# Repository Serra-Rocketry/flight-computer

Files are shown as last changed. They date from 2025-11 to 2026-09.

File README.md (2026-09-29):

# Avionics — Onboard Computer

> **v2.0 Flight Computer** for Serra Rocketry (#11 - Dedalo).
>
> OOP + FreeRTOS + 4-state FSM, validated against real flight data.
> Built for the ESP32-S3.

## Overview

Real-time avionics firmware for a sounding rocket. Runs on an **ESP32-S3**
under FreeRTOS, reading barometric (BMP585), inertial (LSM6DS3) and GPS
(NEO-8M) sensors to detect flight events and deploy the parachute at apogee.

- **Flight state machine**: IDLE → ASCENT → DESCENT → LANDED, with sub-event
  flags (liftoff, burnout, apogee, freefall, parachute)
- **Parachute deployment**: Apogee + stable negative Vz, 3-cycle
  confirmation, 50 m ground guard — validated against RocketPy + real flight data points
- **Telemetry**: 22-field CSV over LoRa @ 915 MHz to ground receiver
- **Logging**: SD card (primary) with LittleFS flash fallback
- **Safety**: NaN/Inf rejection, sensor fallback, TWDT watchdog, multi-condition parachute logic

## Architecture

```
firmware/
├── firmware.ino          # setup()/loop() — orchestrates init*Task()
├── config.h              # Pins, thresholds, radio parameters
├── sensors/              # ISensor implementations (BMP585, LSM6DS3, GPS)
├── flight/               # FreeRTOS tasks + FlightStateMachine
├── modules/              # Actuators/peripherals (servo, LoRa, buzzer, FS)
└── docs/architecture.md  # v2.0 architecture (consolidated from REFACTORING_PLAN.md)
```

Two FreeRTOS cores with queue-based communication:

| Core  | Task | Priority | Rate  | Responsibility |
| ----- | --- | --- | ----- | --- |
| **1** | `FlightControlTask` | 20 | 5 Hz  | Sensors + FSM + parachute + watchdog  |
| **0** | `TelemetryTask` | 5 | 5 Hz  | GPS enrichment + LoRa + file + Serial |
| **0** | `LoggerTask` | 1 | — | Async log queue with level filter |

## Quick Start

### Arduino IDE (recommended)

1. Board: **ESP32-S3 Dev Module** (enable "USB CDC On Boot")
2. Open `firmware/firmware.ino`
3. Install libraries: `Adafruit BMP5xx`, `Adafruit LSM6DS3`, `TinyGPS++`,
   `ESP32Servo`, `LoRa by Sandeep Mistry`
4. Compile (`Ctrl+R`) and upload (`Ctrl+U`)

### Validate without hardware

```bash
python3 extras/FSM_tester/FSM_Tester.py       # FSM against 1,873 real data points
python3 extras/validate_telemetry_format.py    # 22-field telemetry alignment
```

## Key Specifications

| Parameter | Value |
| --- | --- |
| FlightControl rate | 5 Hz (200 ms) |
| Telemetry rate | 5 Hz (200 ms) |
| Parachute confirm  | 3 consecutive Vz < −2 m/s |
| Ground guard | 50 m AGL |
| LoRa frequency | 915 MHz (Brazil/Americas ISM) |
| LoRa config | SF7, BW 125 kHz, CR 4/5, CRC on, +17 dBm |
| Storage | SD card (SPI) → LittleFS fallback |
| Sensor queue | 25 slots (∼2.4 KB) |
| Log queue | 50 slots (∼7.2 KB) |

## Documentation

- [`docs/software.md`](docs/software.md) — Software architecture
|- [`docs/hardware.md`](docs/hardware.md) — Hardware specs, pinout, BOM
|- [`docs/architecture.md`](docs/architecture.md) — Architecture spec (consolidated)
|- [`docs/modules.md`](docs/modules.md) — Module reference
|- [`docs/flowchart.md`](docs/flowchart.md) — FreeRTOS + FSM flow diagram
- [`AGENTS.md`](AGENTS.md) — AI agent coding guide
- [`CONTRIBUTING.md`](CONTRIBUTING.md) — How to contribute

## Repository Layout

```
firmware/   v2.0 firmware (OOP + FreeRTOS + FSM)
test/       Hardware validation sketches (sensors, servo, FSM)
docs/       software.md, hardware.md, telemetry-format.md, flowchart.md
hardware/   KiCad schematic + PCB + BOM
extras/     Scripts, FSM tester, format validator, emergency deploy
```

## Status

All refactoring plan phases are **complete** — v2.0 is fully implemented and
documented. See [`CHANGELOG.md`](CHANGELOG.md) for the full release history.

## Team

Serra Rocketry — IPRJ/UERJ

## License

This project is licensed under the MIT License - see the [LICENSE](LICENSE) file for details.

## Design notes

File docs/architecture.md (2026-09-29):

# Architecture — Flight Computer v2.0

Architecture specification for the v2.0 firmware (OOP + FreeRTOS + 4-state FSM).
Consolidates the former `firmware/REFACTORING_PLAN.md` into a living reference.

## Overview

The v2.0 firmware migrates from the v1.0 procedural architecture to an
object-oriented design with selective POO (sensors only) and a strict
FreeRTOS multi-task separation between safety-critical (FSM + deploy) and
non-critical (telemetry/logging) paths.

**Hardware**: ESP32-S3 DevKitC-1-N8R8 (primary). ESP32-C3 SuperMini for the
emergency backup board (`extras/emergency/`).

## Design Decisions

| Aspect | Decision | Rationale |
|---|---|---|
| OOP | Selective | Only sensors that change became classes |
| FSM | Enum/Switch | Simple, low overhead |
| FreeRTOS | 3 Tasks | Separation: FSM (5 Hz) / Telemetry (5 Hz) / Logger |
| Migration | Big Bang | Full refactor in one pass |
| Tests | Hardware + Python | No C++ unit-test infra; FSM validated via Python port |
| Queue sizes | 25 (sensor), 50 (log) | Covers worst case with margin |
| Watchdog | 5s, armed inside FlightControlTask | Avoids TWDT armed with no task to reset it |
| Logging | Queue-based + Serial filter | Verbose dev, filtered in production |

## Architecture (post-5Hz fix)

### Directory layout

```
firmware/
├── firmware.ino                    # Entry point (setup + init*Task)
├── config.h                        # Pins, thresholds, radio/storage params
├── config.cpp                      # Config helpers
├── sensors/                        # OOP sensor abstraction (headers)
│   ├── ISensor.h                   # Abstract interface
│   ├── BMP585Sensor.h              # Barometer (alt, press, temp, Vz)
│   ├── LSM6DS3Sensor.h             # IMU (6-axis)
│   └── GPSModule.h                 # GNSS (non-blocking NMEA)
├── flight/                         # FSM + FreeRTOS tasks (headers)
│   ├── SensorData.h                # Shared structs + FlightState enum
│   ├── FlightStateMachine.h        # 4-state FSM + 7 sub-event flags
│   ├── FlightControlTask.h         # Task 1 — 5 Hz, Core 1, priority 20
│   ├── TelemetryTask.h             # Task 2 — 5 Hz, Core 0, priority 5
│   └── LoggerTask.h                # Task 3 — low priority
├── modules/                        # Actuators/peripherals (headers)
│   ├── parachute_module.h          # Servo owner
│   ├── lora_module.h               # 915 MHz radio
│   ├── buzzer_module.h             # Status tones
│   └── filesystem_module.h         # SD + LittleFS fallback
├── *.cpp                           # Implementations at sketch root
└── REFACTORING_PLAN.md             # This document (legacy source)
```

> `.cpp` files live at the sketch root because Arduino IDE only compiles
> sources at the root of the `.ino` sketch folder. Headers are organized in
> subfolders; PlatformIO can use `src/` with subdirectories natively.

### FreeRTOS task layout

| Core | Task | Priority | Rate | Responsibility |
|---|---|---|---|---|
| 1 | `taskFlightControl` | 20 (HIGH) | **5 Hz** (200 ms) | Sensors + FSM + deploy + queue + TWDT |
| 0 | `taskTelemetry` | 5 (LOW) | 5 Hz (200 ms) | GPS + queue drain + LoRa + storage + Serial |
| 0 | `taskLogger` | 1 | event | Async log queue consumer |

Inter-task communication via queues only — no shared variables:

- `sensorDataQueue` (25 slots) — FlightControl → Telemetry
- `logQueue` (50 slots) — any task → Logger

### Key tuning parameter: 5 Hz flight loop

> **Context**: Flight #51 (Thonyan, 2026-09-03) descended ballistically —
> parachute never deployed. Root cause: the flight loop ran at 50 Hz while the
> BMP585 effective conversion rate was ~25 Hz. `vz` alternated between 0.00
> (stale cycle) and 2×real (double step over the 20 ms dt). Both
> `PARACHUTE_CONFIRM_CYCLES=3` and `FREEFALL_BACKSTOP_CYCLES=50` — both
> consecutive-cycle gates — never survived the interleaved zeros.

**Fix** (`d0865ee`, `c5dd591`): `FLIGHT_CONTROL_PERIOD_MS` 20 → 200 ms.
All cycle-count constants rescaled to preserve the same **absolute times**:

| Constant | 50 Hz (old) | 5 Hz (new) | Absolute time |
|---|---|---|---|
| `FREEFALL_BACKSTOP_CYCLES` | 50 | 5 | 1.0 s |
| `BARO_STALE_SUSTAIN_CYCLES` | 125 | 13 | 2.6 s |
| `ARM_REZERO_SUSTAIN_CYCLES` | 150 | 15 | 3.0 s |
| `BARO_GLITCH_SUSTAIN_CYCLES` | 50 | 5 | 1.0 s |
| `LIFTOFF_ALT_CONFIRM_CYCLES` | 3 | 1 | 200 ms |
| `PARACHUTE_CONFIRM_CYCLES` | 3 | 3 | 0.6 s (unchanged — time-based) |

`LIFTOFF_CONFIRM_MS` (100 ms) and `LIFTOFF_CONFIRM_MAX_GAP_MS` (60 → 200 ms)
are per-time; `PARACHUTE_CONFIRM_CYCLES` is a count (3 = 600 ms at 5 Hz).

**Validation**: `extras/FSM_tester/validate_fsm_5hz.py` reproduces the failure
numerically — at 50 Hz with stale interleaving, deploy = `None` (blocked);
at 5 Hz, deploy at 317 m, +0.6 s after apogee, matching the real flight.

## Flight State Machine

4 outer states with internal sub-event flags (set once, diagnostic only):

| Outer state | Sub-events tracked |
|---|---|
| `IDLE` | — |
| `ASCENT` | `liftoff`, `burnout` |
| `DESCENT` | `apogee`, `freefall` |
| `LANDED` | `parachute` |

### Transitions

| From | To | Trigger |
|---|----|---|
| IDLE | ASCENT | `detectLiftoff()`: totalAccel > 15 m/s² sustained via `LIFTOFF_CONFIRM_MS` (100 ms) |
| ASCENT | DESCENT | `detectApogee()`: \|vz\| < 1.0 m/s (zero crossing / peak) |
| DESCENT | LANDED | `detectLanded()`: \|vz\| < 0.5 m/s and altitude < 2 m |

### Deploy logic (Option A — at apogee, not descent)

Parachute deploy is **not** a state transition — it is queried by
`FlightControlTask` via `detectParachute()`:

```cpp
bool FlightStateMachine::detectParachute(float height, float vz) const {
  if (height < PARACHUTE_MIN_ALTITUDE) return false;   // 50 m ground guard
  if (vz < PARACHUTE_CONFIRM_VZ) {                     // -2.0 m/s
    return (_parachuteConfirmCount >= PARACHUTE_CONFIRM_CYCLES);  // 3 cycles
  }
  return false;
}
```

Deploy is invoked by `FlightControlTask` when the FSM signals confirmation,
via `parachute_module`'s `ParachuteServo`. Validated against RocketPy
(apogee 951 m → deploy 949.5 m) and real flight (apogee 272 m → deploy 268 m).

### Safety validation

| Test | Scenario | Result |
|---|---|---|
| `validate_fsm_5hz.py` | 50 Hz stale-sensor model reproduces ballistic failure | PASS (deploy = None at 50 Hz, deploy at 317 m at 5 Hz) |
| `validate_50hz_noise.py` | Quantization noise up to 20× real | PASS (0 false apogees, 0 premature deploys) |
| `validate_freefall_backstop.py` | FSM stuck in IDLE/ASCENT | PASS (backstop deploys at apogee) |
| `validate_baro_stale.py` | Barometer frozen mid-flight | PASS (IMU-only deploy at t=19.6s) |
| `validate_watchdog_reboot.py` | TWDT reset during flight | PASS (NVS restores state, deploy on apogee) |
| `validate_arming.py` | Bench vibration false-liftoff | PASS (50 m arming guard survives 22–122 m/s² spikes) |

See also [`docs/modules.md`](modules.md) for the module-by-module API.

## Safety: Dual-layer deploy (FSM-independent backstop)

### Layer 1: FSM Option A
Apogee + 3 consecutive cycles of Vz < -2 m/s, 50 m ground guard.

### Layer 2: Freefall backstop (independent of FSM state)

Implemented in `FlightControlTask::checkFreefallBackstop()` — fires even if
the FSM is alive but stuck in the wrong state (e.g. NVS-restored ASCENT mid-descent,
or FSM in IDLE with no snapshot). Uses its own IIR-filtered accelerometer
(α=0.2), separate from FSM state:

```
totalAccel (IIR α=0.2) < 3.0 m/s²   per 5 consecutive cycles (1.0 s)
        AND vz < -5.0 m/s            (real descent, excludes burnout)
        AND altitude > 50 m          (ground guard)
        → deployParachute()         (idempotent via g_parachuteActuated)
```

**Decisions grounded in real flight data:**
- `vz < -5 m/s` is mandatory: accelerometer drops to ~0g shortly after burnout
  (rocket still ascending). Without this guard, the chute would deploy at ~190 m
  on the way up.
- 1.0 s window: real zero-g windows last 8–131 s; bench vibration spikes are
  transient (22–122 m/s²) and rejected by the window.
- Own IIR filter: works even when FSM state is corrupted.

**Behavior**: fires 1–3 s after FSM deploy in normal flight (never before);
with FSM stuck, deploys at 922 m (simulated) / 255 m (real) — always above
the 50 m floor.

## Safety: Post-watchdog recovery (NVS)

If the TWDT resets the system mid-flight:

1. `FlightStateMachine::begin()` calls `restoreFromNVS()`:
   - No valid snapshot (first boot, or previous flight ended LANDED → clean
     snapshot) → FSM starts fresh in IDLE.
   - Valid snapshot in ASCENT/DESCENT → FSM **resumes from saved state**
     (flags + confirmation counter), and `base_pressure` from launch site is
     restored to the BMP585 → altitude remains **absolute to launch elevation**
     (no re-zeroing at the reboot point).
2. Snapshot saved on every state transition, at deploy, and once at boot.
   `reset()` clears it.
3. `setupServo(keepOpen)`: if the snapshot says chute already deployed, the
   servo is **not** re-closed on boot (closing with chute out mid-air would
   release it).

Validated: `extras/FSM_tester/validate_watchdog_reboot.py` — PASS in 5
simulated flight phases + 4 real flight phases.

**Known limitations**: a reboot during the powered phase re-arms only if
acceleration > 15 m/s² persists after boot; a snapshot from an aborted flight
(before LANDED) can restore ASCENT on the ground — the `PARACHUTE_MIN_ALTITUDE`
guard prevents false deploy.

## Resource usage

| Component | RAM | Flash |
|---|-----|---|
| Base code | ~50 KB | ~200 KB |
| Adafruit libs | ~10 KB | ~50 KB |
| FreeRTOS overhead | ~2 KB | ~20 KB |
| Task stacks (3 × 8 KB avg) | 28 KB | — |
| Queues (25 + 50 slots) | ~8 KB | — |
| Sensor/FSM objects | ~5 KB | — |
| **Total** | **~103 KB** | **~270 KB** |

Available: 512 KB RAM (~20%); 8 MB flash (~3%).

## Change log (from REFACTORING_PLAN.md)

### 2026-08-04 — Freefall backstop (FSM-independent)
`checkFreefallBackstop()`: acc < 3 m/s² (own IIR) for 1.0 s + vz < -5 m/s +
h > 50 m → idempotent deploy. Validated in Python before C++
(`validate_freefall_backstop.py` — scenarios A–D, all PASS).

### 2026-08-04 — Watchdog post-reset recovery (NVS)
FSM persists snapshot to NVS (`Preferences`, namespace `flight`/key `fsm`):
state, flags, confirmation counter, `base_pressure`, `maxAltitude`.
`restoreFromNVS()` in `begin()`. `setupServo(keepOpen)` prevents re-closing
an already-deployed chute. Validated: `validate_watchdog_reboot.py` (9 scenarios).

### 2026-08-05 — Real-flight risk review (5 risks)
- **Risk 1** (barometer freezes mid-flight): resolved — `getLastReadingAgeMs()`
  + IMU-only `checkBaroStaleContingency()` (deploy if baro stale >2 s + acc <3
  m/s² + h > 50 m, validated `validate_baro_stale.py` A–D PASS).
- **Risk 3** (apogee lost to 50 Hz vz noise): not confirmed —
  `validate_50hz_noise.py` shows 100% apogee detection, 0 premature deploys,
  0 missed deploys up to 5 s after apogee.
- **Risk 5** (post-burnout oscillation loses apogee): resolved —
  apogee gate simplified to `|vz| < 1.0` only (removed `az` gate with ~0.81 m/s²
  margin). vz from barometer is immunized against oscillation by construction.

### 2026-05-09 — 5 Hz flight loop (Thonyan #51 fix)
`FLIGHT_CONTROL_PERIOD_MS` 20 → 200. See "Key tuning parameter: 5 Hz flight loop"
above. This is the single change that unblocked apogee deployment for
Dédalo II / Thonyan II.

### 2026-06-24 — All 10 phases complete
v2.0 firmware fully migrated to OOP + FreeRTOS + 4-state FSM. See `CHANGELOG.md`.

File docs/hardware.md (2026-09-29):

# Hardware Documentation - Onboard Computer

## Overview

The onboard computer uses an **ESP32-S3** microcontroller (the v2.0 target
platform) as its core, integrated with a barometric altimeter, GPS, IMU and a
LoRa communication module.

> **Note — prototype vs target**: the early dev firmware ran on an
> ESP32-C3 SuperMini; the v2.0 design (schematic `hardware/electronics/...`)
> uses the ESP32-S3. The pin assignments in `firmware/config.h` now target the
> S3. Re-map if migrating between boards.

## Main Platform

### ESP32-S3 (v2.0 target)

**Specifications**:

- **Processor**: Xtensa LX7 dual-core @ 240 MHz
- **RAM**: 512 KB (SRAM) + PSRAM (see module variant)
- **Flash**: 8 MB (N8R8) or 2 MB (N8R2) — confirm variant on BOM/purchase order
- **Peripherals**: UART, SPI, I2C, GPIO, ADC, Timer, USB-OTG
- **Wireless**: WiFi 802.11b/g/n + Bluetooth 5 (LE)
- **Size**: ESP32-S3-DevKitC-1 form factor

**Used Pins** (from `firmware/config.h`):

```
GPIO 4  → RST_LORA   (LoRa Reset)
GPIO 5  → DIO0_LORA  (LoRa Interrupt / TX-RX done)
GPIO 6  → BUZZER_PIN
GPIO 7  → SERVO_PIN  (Parachute servo PWM)
GPIO 8  → I2C_SDA    (BMP585/BMP280 + LSM6DS3)
GPIO 9  → I2C_SCL    (BMP585/BMP280 + LSM6DS3)
GPIO 10 → SS_LORA    (LoRa Chip Select)
GPIO 11 → LORA_MOSI  (LoRa SPI MOSI)
GPIO 12 → LORA_SCK   (LoRa SPI Clock)
GPIO 13 → LORA_MISO  (LoRa SPI MISO)
GPIO 14 → SD_CS_PIN  (SD Card Chip Select)
GPIO 17 → RX_GPS     (UART RX — GPS TX)  ⚠ bench-measured 2026-08-27, see note
GPIO 18 → TX_GPS     (UART TX — GPS RX)  ⚠ bench-measured 2026-08-27, see note
```

> **GPS pinout note (2026-08-27 bench measurement):** the GPS TX line
> physically arrives on GPIO17, not GPIO18 as previously documented from the
> schematic. `config.h` was corrected (RX_GPS=17, TX_GPS=18) and validated on
> hardware: NMEA at 9600 baud, 11 satellites, 3D fix. Always trust the raw
> sniffer (`test/gps_diag/`) over the schematic comment when they disagree.

**Power Supply**: 3.3V nominal (regulated by LM2596).

## Sensors

### 1. BMP585 - Barometric Pressure Sensor

**Function**: Altitude and atmospheric pressure (vertical velocity derived in firmware).

**Specifications**:

- **Pressure Range**: 300 - 1250 hPa
- **Relative Accuracy**: ±0.06 hPa (typ.)
- **Absolute Accuracy**: ±0.5 hPa (typ.)
- **Interface**: I2C
- **I2C Address**: 0x7E (bench-measured 2026-08-27; factory default is 0x76/0x77
  selected by CSB). **Fallback**: if the BMP585 is absent, the driver
  (`BMP585Sensor`) falls back to a **BMP280** at 0x76/0x77 — same satellite
  pattern (`BME280Sensor.cpp` in the #213 repo).

**Pinout**:

| Pin | Function | Connection |
|-----|---|---|
| VCC | Power | 3.3V |
| GND | Ground | GND |
| SCL | I2C Clock | GPIO 9 |
| SDA | I2C Data | GPIO 8 |

**Assembly**: Breakout direct solder on PCB.

### 2. LSM6DS3 - IMU (Accelerometer + Gyroscope)

**Function**: Acceleration and angular velocity (flight dynamics).

**Specifications**:

- **Accelerometer**: ±2, ±4, ±8, ±16 g (configurable)
- **Gyroscope**: ±125, ±250, ±500, ±1000, ±2000 °/s
- **Interface**: I2C
- **I2C Address**: 0x6B (bench-measured 2026-08-27; SDO strap selects 0x6A/0x6B)

**Pinout**:

| Pin | Function | Connection |
|-----|---|---|
| VCC | Power | 3.3V |
| GND | Ground | GND |
| SCL | I2C Clock | GPIO 9 |
| SDA | I2C Data | GPIO 8 |

**Assembly**: Breakout direct solder on PCB.

### 3. NEO-8M - GPS Module

**Function**: Geolocation and time synchronization.

**Specifications**:

- **Sensitivity**: -167 dBm (tracking)
- **Acquisition**: Cold ~26s, Hot ~1s
- **Accuracy**: ±2.5 m
- **Update Rate**: up to 10 Hz
- **Protocol**: NMEA 0183
- **Interface**: Serial UART (HardwareSerial, non-blocking in firmware)

**Pinout**:

| Pin | Function | Connection |
|-----|---|---|
| VCC | Power | 3.3V |
| GND | Ground | GND |
| RX | Serial RX | GPIO 21 (TX_GPS) |
| TX | Serial TX | GPIO 20 (RX_GPS) |

**Features**:

- Integrated ceramic antenna
- Frequency: L1 (1575.42 MHz)
- Constellations: GPS, GLONASS, Galileo, BeiDou

**Assembly**: Breakout direct solder on PCB.

### 4. RFM95W - LoRa Module

**Function**: Long-range wireless telemetry to the recovery receiver.

**Specifications**:

- **Frequency**: 915 MHz ISM (Americas/Brazil; matches receiver-lora)
- **Range**: ~4 km (open field, ideal conditions)
- **Data Rate**: 0.3 - 37.5 kbps (SF/BW dependent)
- **Transmit Power**: +17 dBm (firmware setting)
- **Sensitivity**: -139 dBm (SF12, BW 125 kHz)
- **Interface**: SPI

**Configuration (firmware `config.h` + `lora_module.h`)**:

- Frequency: 915 MHz
- Sync Word: 0xF3
- Spreading Factor: 7
- Bandwidth: 125 kHz
- Coding Rate: 4/5
- CRC: enabled

**Pinout** (matches `config.h` — SPI bus is remapped via `SPI.begin(4,2,3,5)` in `setupLoRa()`):

| Pin | Function | Connection |
|-----|---|---|
| VCC | Power | 3.3V |
| GND | Ground | GND |
| SCK | SPI Clock | GPIO 4 (LORA_SCK) |
| MOSI| SPI Data | GPIO 3 (LORA_MOSI) |
| MISO| SPI Data | GPIO 2 (LORA_MISO) |
| NSS | SPI CS | GPIO 5 (SS_LORA) |
| NRST| Reset | GPIO 6 (RST_LORA) |
| DIO0| TX/RX Int| GPIO 7 (DIO0_LORA) |

**Assembly**: Breakout direct solder on PCB.

### 5. MicroSD Card — Data Logging

**Function**: Primary flight-data storage. The firmware writes the 22-field
CSV telemetry log here; if the card is absent or fails to mount, logging
automatically falls back to LittleFS (internal flash).

**Interface**: SPI (shares the same SCK/MOSI/MISO bus as the RFM95W, with an
independent chip-select line).

**Pinout**:

| Pin | Function | Connection |
|-----|---|---|
| VCC | Power | 3.3V |
| GND | Ground | GND |
| SCK | SPI Clock | GPIO 4 (shared with LoRa) |
| MOSI| SPI Data | GPIO 3 (shared with LoRa) |
| MISO| SPI Data | GPIO 2 (shared with LoRa) |
| CS  | SPI CS | GPIO 12 (SD_CS_PIN) |

**Note**: Because SD and LoRa share one SPI bus, `setupStorage()` (SD probe)
runs *before* `setupLoRa()` inside `initTelemetryTask()`, and both backends
use the same `SPI` object remapped to GPIO 4/3/2. A card present at boot is
preferred; LittleFS is the safety net.

## Actuators

### Parachute Servo

**Function**: Release the parachute mechanism at apogee (FSM Option A).

**Specifications**:

- **Type**: Standard 5V servo with metal gears
- **Torque**: ~4.8 kg/cm @ 5V
- **Speed**: ~0.23 s/60°
- **Weight**: ~9 g

**Pinout**:

| Wire | Function |
|---|---|
| Brown | Ground |
| Red | +5V |
| Yellow/Orange | PWM Signal (GPIO 10, SERVO_PIN) |

**Positions** (see `parachute_module.h`):

- Closed (pre-flight): `CLOSED_POS`
- Open (deployed): `OPEN_POS`

### Buzzer - Audio Signaling

**Function**: Initialization status indicator.

**Specifications**:

- **Type**: Active buzzer (5V)
- **Frequency**: ~2.7 kHz
- **Volume**: ~85 dB
- **Current**: ~30 mA

**Pinout**:

- Positive → 5V (via current-limiting resistor)
- Negative → GPIO 11 (BUZZER_PIN)

**Signals**:

- 3 short beeps = Initialization failure
- Beep sequence = Successful initialization

## Power Supply

### LM2596 - DC-DC Step Down Converter

**Function**: Regulate battery voltage to 3.3V / 5V.

**Specifications**:

- **Input**: 4.5 - 40V
- **Output 1**: 3.3V @ 3A (ESP32, I2C sensors)
- **Output 2**: 5V @ 3A (servo, buzzer, LoRa)
- **Frequency**: 150 kHz
- **Efficiency**: ~85%

### Batteries

**Configuration**: 3x 18650 in parallel

- **Nominal Voltage**: 3.7V
- **Capacity**: ~6000 mAh
- **Estimated Autonomy**: ~4-6 hours

## Printed Circuit Board (PCB)

### KiCad Files

- **[CDB.kicad_pro](../hardware/CDB/CDB.kicad_pro)** - Project file
- **[CDB.kicad_sch](../hardware/CDB/CDB.kicad_sch)** - Schematic
- **[CDB.kicad_pcb](../hardware/CDB/CDB.kicad_pcb)** - Board layout
- **[CDB.step](../hardware/CDB/CDB.step)** - 3D model

### Connectors

- **J2**: Servo motor (3 pins)
- **Power Connector**: 2 pins for 18650

### Approximate Dimensions

- **Length**: 125 mm
- **Width**: 50 mm
- **Height** (with components): ~30 mm

## Component List (BOM)

See [CDB_bom.md](../hardware/CDB_bom.md) for the complete list.

### Main Electronic Components

| Label | Component | Quantity | Function |
|---|---|---|---|
| A2 | ESP32-S3 (DevKitC-1) | 1 | Microcontroller (v2.0 target; N8R8 or N8R2 — confirm) |
| A3 | BMP585 Breakout | 1 | Pressure/altitude sensor |
| — | LSM6DS3 Breakout | 1 | IMU |
| M3 | LM2596 | 1 | Voltage regulator |
| M4 | NEO-8M | 1 | GPS |
| RFM95W1 | RFM95W LoRa | 1 | Wireless telemetry |
| SD1 | MicroSD card module | 1 | Flight-data logging (SPI, GPIO 12 CS) |
| J1 | 5V Buzzer | 1 | Signaling |
| J2 | Servo motor | 1 | Parachute control |

### Passive Components

- Capacitors: 100 nF, 10 μF, 220 μF
- Resistors: 1k, 10k, 100k Ohm
- Connectors: Pins, JST

## Block Diagram

```
┌─────────────────────────────────────────────────────────────┐
│                  ONBOARD COMPUTER                            │
├─────────────────────────────────────────────────────────────┤
│  ┌──────────┐  ┌──────────┐  ┌──────────┐  ┌──────────┐    │
│  │ BMP585   │  │ LSM6DS3  │  │ NEO-8M   │  │ RFM95W   │    │
│  │Barometer │  │   IMU    │  │   GPS    │  │  LoRa    │    │
│  └────┬─────┘  └────┬─────┘  └────┬─────┘  └────┬─────┘    │
│       │ I2C         │ I2C         │ UART         │ SPI     │
│       └─────────────┼─────────────┼──────────────┤        │
│              ┌──────┴─────────────┴──────┬────────┴────┐   │
│              │      ESP32-S3 (DevKitC-1)   │             │   │
│              │  FreeRTOS: FlightControl  │  Telemetry  │   │
│              │  (50Hz) → FSM → Servo     │  (5Hz) LoRa │   │
│              └────┬──────────┬───────────┴─────┬───────┘   │
│        GPIO PWM  │          │  GPIO BUZZER     │ SPI       │
│    ┌─────────────▼┐    ┌────▼──────┐    ┌──────▼────┐      │
│    │ Servo Motor  │    │ Buzzer    │    │ RFM95W    │      │
│    └──────────────┘    └───────────┘    └───────────┘      │
│  ┌──────────────────────────────────────────────────────┐  │
│  │          LM2596 DC-DC Converter                      │  │
│  │  Input: 3.7V (3x18650 parallel)  →  Output: 3.3V and 5V  │  │
│  └──────────────────────────────────────────────────────┘  │
└─────────────────────────────────────────────────────────────┘
```

## Support/Test Code

Individual test code is in [../test/](../test/):

- `test/basico/basico.ino` — general diagnostics
- `test/buzzer/buzzer.ino` — buzzer
- `test/lora/lora.ino` — LoRa
- `test/testeGPS/testeGPS.ino` — GPS
- `test/servo/servo.ino` — servo
- `test/LittleFS/LittleFS.ino` — storage
- `test/FSM/FSM.ino` — FSM reference (validated)

## Preliminary Tests

- Check continuity with multimeter
- Power on and check LEDs/buzzer
- Use basic test code

## Operation Notes

- **Encapsulation**: isolating capsule inside rocket
- **Shock**: Maximum acceleration tolerance not yet measured

## References

- [ESP32-S3 Datasheet](https://www.espressif.com/sites/default/files/documentation/esp32-s3_datasheet_en.pdf)
- [BMP585 Datasheet](https://www.bosch-sensortec.com/products/environmental-sensors/pressure-sensors/bmp585/)
- [LSM6DS3 Datasheet](https://www.st.com/resource/en/datasheet/lsm6ds3.pdf)
- [NEO-8M GPS Module](https://www.u-blox.com/en/product/neo-8m-series)
- [RFM95W LoRa Module](https://www.semtech.com/products/wireless-rf/lora-transceivers/rfm95w)

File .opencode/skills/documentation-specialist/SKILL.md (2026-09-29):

---
name: documentation-specialist
description: Technical writer and documentation specialist for embedded systems and aerospace projects.
license: MIT
compatibility: opencode
---

## Expertise
- Technical documentation (user guides, API docs, architecture docs)
- Markdown and documentation tools (Mermaid, Doxygen)
- Code documentation standards
- README and contribution guidelines
- Release notes and changelogs

## Responsibilities
1. **Maintain Project Documentation**
   - Keep README.md up to date
   - Update CHANGELOG.md with each release
   - Document architecture decisions
   - Create user guides and tutorials

2. **Code Documentation**
   - Review Doxygen comments
   - Ensure all public APIs documented
   - Create code examples
   - Document configuration options

3. **Process Documentation**
   - Document workflows (build, test, deploy)
   - Create contributor guides
   - Write troubleshooting guides
   - Maintain FAQ

## Project Documentation Structure

```
flight-computer/
├── README.md                    # Project overview
├── CHANGELOG.md                 # Version history
├── CONTRIBUTING.md              # How to contribute
│
├── docs/
│   ├── hardware.md              # Hardware specifications
│   ├── software.md              # Software architecture
│   ├── flowchart.md             # System flowcharts
│   └── CDB.png                  # Block diagram
│
├── firmware/
│   ├── MODULOS.md               # Module documentation
│   ├── REFACTORING_PLAN.md      # v2.0 architecture
│   └── [code files with Doxygen comments]
│
└── extras/
    └── FSM_tester/
        └── explicacao.md        # FSM explanation
```

## Documentation Standards

### README.md Structure
```markdown
# Project Name

[Badge: Build Status] [Badge: License] [Badge: Version]

## Overview
Brief description of the project (2-3 sentences)

## Features
- Feature 1
- Feature 2

## Hardware Requirements
- Component 1
- Component 2

## Software Requirements
- Library 1
- Library 2

## Quick Start
1. Step 1
2. Step 2

## Documentation
- [Hardware Guide](docs/hardware.md)
- [Software Guide](docs/software.md)

## Contributing
See [CONTRIBUTING.md](CONTRIBUTING.md)

## License
[License information]

## Team
Team #100 - Serra Rocketry
```

### CHANGELOG.md Format
**Follow**: [Keep a Changelog](https://keepachangelog.com/)

```markdown
# Changelog

All notable changes to this project will be documented in this file.

The format is based on [Keep a Changelog](https://keepachangelog.com/en/1.0.0/),
and this project adheres to [Semantic Versioning](https://semver.org/spec/v2.0.0.html).

## [Unreleased]

### Added
- New feature X

### Changed
- Modified behavior Y

### Fixed
- Bug Z

## [2.0.0] - 2026-XX-XX

### Added
- FreeRTOS multi-task architecture
- 7-state FSM with validated thresholds
- BMP585 and LSM6DS3 sensor support
- OOP sensor abstractions (ISensor interface)

### Changed
- Migrated from procedural to OOP design
- Replaced BMP280 with BMP585
- Replaced MPU6050 with LSM6DS3

### Removed
- Old procedural sensor modules

## [1.0.0] - 2026-01-27

### Added
- Initial release
- BMP280 barometric sensor support
- MPU6050 IMU support
- GPS NEO-6M integration
- LoRa telemetry (RFM95W)
- Parachute deployment logic
- LittleFS data logging
- WiFi AP for data recovery

[Unreleased]: https://github.com/team100/flight-computer/compare/v2.0.0...HEAD
[2.0.0]: https://github.com/team100/flight-computer/compare/v1.0.0...v2.0.0
[1.0.0]: https://github.com/team100/flight-computer/releases/tag/v1.0.0
```

### Code Documentation (Doxygen)

#### File Header
```cpp
/**
 * @file BMP585Sensor.h
 * @brief BMP585 barometric pressure sensor driver with altitude calculation
 * 
 * This module provides an interface to the Bosch BMP585 barometric pressure
 * sensor. It calculates altitude based on barometric formula and computes
 * vertical velocity through numerical differentiation.
 * 
 * @author Team #100 - Serra Rocketry
 * @date 2026-04-01
 * @version 2.0.0
 * 
 * Hardware Requirements:
 * - BMP585 sensor connected via I2C
 * - I2C address: 0x77 (SDO high) or 0x76 (SDO low)
 * - Pull-up resistors: 4.7kΩ (internal to ESP32-C3)
 * 
 * Usage Example:
 * @code
 * BMP585Sensor baro;
 * 
 * void setup() {
 *   if (!baro.begin()) {
 *     Serial.println("Sensor initialization failed");
 *   }
 * }
 * 
 * void loop() {
 *   baro.update();
 *   float alt = baro.getAltitude();
 *   float vz = baro.getVerticalVelocity();
 * }
 * @endcode
 * 
 * @see firmware/REFACTORING_PLAN.md for architecture details
 * @see docs/hardware.md for wiring diagram
 */
```

#### Function Documentation
```cpp
/**
 * @brief Initializes the BMP585 sensor and calibrates base pressure
 * 
 * This function performs the following steps:
 * 1. Establishes I2C communication with sensor
 * 2. Verifies sensor ID (0x50 for BMP585)
 * 3. Configures oversampling and IIR filter
 * 4. Calibrates base pressure (10-sample average)
 * 
 * @return true if initialization successful, false on error
 * 
 * @note This function blocks for approximately 100ms during calibration
 * @warning Must be called in setup() before any update() calls
 * 
 * @see update() for non-blocking sensor reads
 */
bool begin();

/**
 * @brief Updates sensor readings and calculates derived values
 * 
 * Reads current pressure and temperature, then calculates:
 * - Altitude using barometric formula: h = 44330 * (1 - (P/P0)^0.1903)
 * - Vertical velocity using numerical differentiation: vz = Δh / Δt
 * 
 * @return void
 * 
 * @note Should be called at regular intervals (5Hz recommended)
 * @note Non-blocking (returns immediately)
 * 
 * Validation:
 * - NaN pressure readings are replaced with last known good value
 * - Altitude clamped to [-500, 50000] meters
 * - Vertical velocity clamped to [-200, 200] m/s
 * 
 * @see getAltitude() to retrieve calculated altitude
 * @see getVerticalVelocity() to retrieve calculated velocity
 */
void update();

/**
 * @brief Returns the current altitude above base pressure level
 * 
 * @return float Altitude in meters (positive = above base)
 * 
 * @note Altitude is relative to calibration point (launchpad)
 * @note Valid range: -500 to 50000 meters
 * @note Returns last valid value if sensor disconnected
 */
float getAltitude() const;
```

### Architecture Documentation

#### Decision Record Template
**File**: `docs/adr/001-freertos-migration.md`

```markdown
# ADR 001: Migrate to FreeRTOS Architecture

**Status**: Accepted  
**Date**: 2026-03-15  
**Deciders**: Team #100  

## Context
Current v1.0 firmware uses single-threaded Arduino loop() running at 5Hz.
This creates several issues:
1. Slow FSM response time (200ms loop period)
2. Cannot prioritize flight-critical tasks
3. Telemetry logging blocks flight control
4. Underutilizes ESP32 dual-core processor

## Decision
Migrate to FreeRTOS multi-task architecture with 3 tasks:
- **FlightControl**: 50Hz, Core 1, Priority 20 (flight-critical)
- **Telemetry**: 5Hz, Core 0, Priority 5 (non-critical)
- **Logger**: Low priority, Core 0 (background)

## Rationale
- **Real-time response**: 20ms FSM update vs 200ms previously
- **Prioritization**: Flight safety takes precedence over logging
- **Core separation**: Flight logic isolated from I/O operations
- **Scalability**: Easy to add tasks (e.g., camera control)

## Consequences

### Positive
- 10x faster FSM response time
- Flight control never blocked by slow operations
- Better CPU utilization (both cores active)
- Industry-standard RTOS patterns

### Negative
- Increased complexity (task synchronization)
- Higher RAM usage (~15KB for RTOS overhead)
- Requires mutex/queue understanding
- Longer development time (estimated +8 hours)

## Alternatives Considered
1. **Keep single-threaded** - Rejected: Too slow for safety-critical FSM
2. **Custom cooperative scheduler** - Rejected: Reinventing the wheel
3. **Bare metal dual-core** - Rejected: Complex synchronization

## Implementation
See `firmware/REFACTORING_PLAN.md` Phase 7 for details.

## References
- ESP32 Technical Reference Manual, Chapter 3 (RTOS)
- FreeRTOS Documentation: Task Priorities
- Similar implementation: Teensy Flight Computer (MIT Rocket Team)
```

### Mermaid Diagrams

#### FSM State Diagram
```markdown
## Flight State Machine

```mermaid
stateDiagram-v2
    [*] --> IDLE
    IDLE --> LIFTOFF: totalAccel > 15 m/s²<br/>height > 5m
    
    LIFTOFF --> BURNOUT: az < -8 m/s² OR<br/>totalAccel < 2 m/s²
    
    BURNOUT --> APOGEE: |vz| < 1 m/s AND<br/>az < -0.1 m/s²
    
    APOGEE --> FREEFALL: totalAccel < 11.5 m/s² AND<br/>vz < -5 m/s
    
    FREEFALL --> PARACHUTE: altitude < 750m OR<br/>|vz| > 80 m/s
    
    PARACHUTE --> LANDED: |vz| < 0.5 m/s AND<br/>height < 10m
    
    LANDED --> [*]
    
    note right of IDLE
        Initialize sensors
        Calibrate base pressure
    end note
    
    note right of PARACHUTE
        Deploy parachute
        Start WiFi AP
        Beacon buzzer
    end note
\```
```

#### Task Interaction Diagram
```markdown
## FreeRTOS Task Architecture

```mermaid
graph TB
    subgraph "Core 1 - Flight Critical"
        FC[FlightControl Task<br/>50Hz, Priority 20]
        FSM[Flight State Machine]
        SENS[Sensor Updates]
        PARA[Parachute Control]
        
        FC --> FSM
        FC --> SENS
        FSM --> PARA
    end
    
    subgraph "Core 0 - Non-Critical"
        TEL[Telemetry Task<br/>5Hz, Priority 5]
        LOG[Logger Task<br/>Low Priority]
        
        TEL --> LORA[LoRa Transmit]
        TEL --> SERIAL[Serial Output]
        LOG --> FS[File System]
    end
    
    subgraph "Shared Resources"
        QUEUE[(Sensor Data Queue)]
        MUTEX{Altitude Mutex}
    end
    
    FC -->|xQueueSend| QUEUE
    TEL -->|xQueueReceive| QUEUE
    
    FC -->|xSemaphoreTake| MUTEX
    TEL -->|xSemaphoreTake| MUTEX
    
    style FC fill:#f96,stroke:#333,stroke-width:2px
    style TEL fill:#9cf,stroke:#333,stroke-width:2px
    style LOG fill:#9cf,stroke:#333,stroke-width:2px
\```
```

## Documentation Review Checklist

### For New Features
- [ ] README.md updated with feature description
- [ ] CHANGELOG.md updated (Unreleased section)
- [ ] API documentation (Doxygen comments)
- [ ] Usage examples provided
- [ ] Hardware requirements documented (if applicable)
- [ ] Configuration options explained

### For Bug Fixes
- [ ] CHANGELOG.md updated (Fixed section)
- [ ] Root cause documented in issue/PR
- [ ] Prevention strategy explained

### For Refactoring
- [ ] Architecture Decision Record created
- [ ] Migration guide provided
- [ ] Breaking changes documented
- [ ] CHANGELOG.md updated (Changed section)

## Tools

### Generate Doxygen Docs
```bash
# Install Doxygen
sudo apt install doxygen graphviz

# Generate documentation
cd firmware
doxygen Doxyfile

# View in browser
firefox html/index.html
```

### Mermaid Live Editor
https://mermaid.live/

### Markdown Linting
```bash
# Install markdownlint
npm install -g markdownlint-cli

# Lint documentation
markdownlint docs/**/*.md
```

## Resources
- Project documentation: `docs/`
- Doxygen manual: https://www.doxygen.nl/
- Mermaid syntax: https://mermaid.js.org/
- Keep a Changelog: https://keepachangelog.com/
- Semantic Versioning: https://semver.org/

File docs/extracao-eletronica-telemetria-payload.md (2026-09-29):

# Extração — Setor de Eletrônica, Telemetria e Payload

> **Fonte:** repositório `flight-computer` (branch `dev-2026`, HEAD `130149c`)
> **Para:** preenchimento do relatório do setor (competição 7ª LASC)
> **Data da extração:** 2026-08-06
> **Status:** v2.0 implementada (firmware completo em OOP); eletrônica em
> transição — schematic v2.0 existe mas PCB de voo ainda não roteada

---

## 1. System Architecture & CONOPS

### 1.1 Descrição geral do sistema eletrônico

O computador de voo é um sistema embarcado baseado em **ESP32-S3**
(DevKitC-1 N8R2), dois núcleos, 8 MB Flash, 2 MB PSRAM, executando
**FreeRTOS** com arquitetura orientada a objetos (v2.0). O sistema é
projetado para missões de foguetes suborbitais de curta duração (até
20 minutos), com a responsabilidade crítica de **abrir o paraquedas no
apogeu** de forma autônoma e sem feedback de confirmação mecânica.

O projeto transita de uma PCB protótipo (ESP32-C3 SuperMini + BME280 +
ICM-20602, uma camada, 4 componentes SMD) para a placa definitiva v2.0
(ESP32-S3 + BMP585 + LSM6DS3 + GPS M8N + LoRa 915 MHz + SD + step-down),
cujo schematic existe mas ainda não foi roteado. Durante a fase atual, o
firmware v2.0 é validado na placa DevKitC em bancada.

**Princípios de projeto do firmware:**
- Todas as decisões de deploy do paraquedas são **one-shot** (uma única
  vez, idempotente) e baseadas em **múltiplas camadas de redundância**
  independentes entre si.
- Dados de voo são gravados localmente (SD ou flash interna) como fonte
  primária; a telemetria LoRa é *best-effort* — o sistema nunca para de
  gravar por causa do link de rádio.
- Se qualquer componente de sensor falha, o sistema **não para** — usa
  fallbacks para os últimos valores válidos ou sensores redundantes.

### 1.2 Subsistema de hardware

| Subsistema | Componente | Função | Interface | Observações |
|---|---|---|---|---|
| Processador | ESP32-S3 DevKitC-1 N8R2 | Controle central,FreeRTOS, 2 núcleos | — | 240 MHz, 512 KB SRAM, 8 MB Flash, 2 MB PSRAM |
| Barômetro | BMP585 (Bosch) | Altitude barométrica, pressão, temperatura, Vz derivado no firmware | I2C (0x77) | 300–1250 hPa; ±0,5 hPa absoluta, ±0,06 hPa relativa; resolução ~0,01 hPa |
| IMU | LSM6DS3 (STMicroelectronics) | Aceleração (±16 g) e giroscópio (±2000 °/s) | I2C (0x6A) | Usado como sensor primário para detecção de queda livre (backstop) e contingência do barômetro congelado |
| GPS | u-blox NEO-8M / M8N | Geolocalização (lat/lon/alt) e tempo (nome do arquivo CSV) | UART (NMEA, não-bloqueante) | Multi-constelação: GPS + GLONASS + Galileo + BeiDou; sensibilidade −167 dBm; fix cold 26 s, hot 1 s |
| Telemetria | RFM95W HopeRF | Link de rádio LoRa 915 MHz (Brasil/Américas) | SPI (SCK=4, MISO=2, MOSI=3, CS=5, RST=6, DIO0=7) | SF7, BW125 kHz, CR 4/5, CRC on, TX +17 dBm; alcance ~4 km campo aberto |
| Armazenamento primário | MicroSD (SPI) | Gravação CSV 22 campos a 5 Hz (~4 KB/s) | SPI (bus compartilhado com LoRa, CS=12) | Cartão class 10; formato FAT32 |
| Armazenamento fallback | LittleFS (flash interna) | Fallback automático se SD falhar | Interno (NVS flash) | Capacidade limitada (~4 MB); se SD e LittleFS falharem, dados vão apenas para Serial |
| Atuador | Servo metálico ~4,8 kg·cm | Libera a porta do compartimento do paraquedas no apogeu | PWM (GPIO 7) | **50° (fechado) → 135° (ejeção)** — ângulos de bancada 2026-08-27; acionamento one-shot, sem feedback mecânico |
| Sinalização | Buzzer **passivo** | Beeps de status na inicialização (sucesso/falha) e alarme em safe-hold | GPIO 6 | Piezo passivo: exige onda quadrada via `tone()`/LEDC; **ressonância 2700 Hz** (varredura de bancada 27/08) — DC não produz som |
| Potência (estágio 1) | XL4015 step-down 5 A | Conversão DC-DC bateria → 5 V (servo, buzzer, GPS) | — | Substituiu o Mini-560 (27/08) após colapso sob pico do servo na bateria (unidade defeituosa; ver FMECA F16). Dropout ~1,5-2 V (assíncrono) — headroom aperta com 2S em fim de descarga |
| Potência (baterias) | 3× 18650 Li-ion paralelo | Fonte primária de energia | — | 3,7 V nominal, ~6000 mAh total; autonomia estimada 4–6 h |

### 1.3 Arquitetura de software (FreeRTOS)

O firmware é estruturado em três tarefas FreeRTOS concorrentes, duas
executadas no Core 0 (comunicação/armazenamento) e uma no Core 1
(controle de voo em tempo real). A comunicação entre tarefas ocorre
exclusivamente via filas (queues) — não há variáveis compartilhadas entre
tasks, eliminando condições de corrida por construção.

**Tarefa 1 — `taskFlightControl` (Core 1, prioridade 20, 50 Hz)**
Responsabilidade: leitura sequencial dos sensores (BMP585 → LSM6DS3),
execução da FSM, detecção e acionamento do paraquedas, alimentação do
watchdog (TWDT), coleta de métricas de execução (ciclos, overruns, queue
drops, tempo máximo de ciclo). Esta é a tarefa mais crítica do sistema
— sua perda (travamento) ativa o watchdog e provoca reboot, mas o estado
da FSM é restaurado do NVS, garantindo que o deploy possa ocorrer mesmo
após o reboot.

**Tarefa 2 — `taskTelemetry` (Core 0, prioridade 5, 5 Hz)**
Responsabilidade: atualização não-bloqueante do GPS (NMEA feed), drenagem
da fila de sensores (consome apenas a amostra mais recente, descartando
backlog de 200 ms), enriquecimento com fix GPS, montagem do CSV 22 campos
via `snprintf` (uma única conversão — não fragmenta heap), fan-out em três
canais simultâneos: Serial (debug), LoRa (receptor em solo) e arquivo
(SD ou LittleFS). O formato CSV é idêntico ao esperado pelo receptor
`recovery-webui/components/receiver-lora`.

**Tarefa 3 — `taskLogger` (Core 0, prioridade baixa, evento)**
Responsabilidade: recebe mensagens da fila de logs (50 slots) com filtro
de nível e imprime no Serial. Usado para diagnóstico e rastreio de
eventos de segurança (ARM, deploy, erros de watchdog).

**Parâmetros-chave de execução:**

| Parâmetro | Valor | Justificativa |
|---|---|---|
| Período FlightControl | 20 ms (50 Hz) | Resolução suficiente para detectar apogeu com 20 ms de latência (vz muda ~0,5 m/s por ciclo no apogeu) |
| Período Telemetry | 200 ms (5 Hz) | Balanço entre taxa de amostragem para o receptor e janela de TX LoRa |
| Tamanho da fila de sensores | 25 slots | FlightControl produz 10× mais rápido que Telemetry; fila absorve variações de timing |
| Tamanho da fila de logs | 50 slots | Suficiente para burst de logs durante初始化 |
| Stack da FlightControlTask | 8192 bytes | Mínimo necessário para BMP585Sensor + LSM6DS3Sensor + FlightStateMachine + buffers |
| Stack da TelemetryTask | 4096 bytes | GPSModule + montagem de String (snprintf em buffer fixo 256 bytes) |
| Timeout do watchdog | 10 s | Mais longo que o período de voo (~10 s até apogeu), para não reiniciar durante a subida |

### 1.4 Lógica algorítmica de acionamento da recuperação

O sistema de recuperação é a função mais crítica do computador de voo.
Ele é implementado como uma **Finite State Machine (FSM) de 4 estados**
com 7 flags de sub-evento, projetada com múltiplas camadas de defesa
independentes para garantir que o paraquedas abra mesmo em caso de falhas
cascata.

**FSM principal:** `IDLE → ASCENT → DESCENT → LANDED`

**Sub-eventos (flags booleanas, uma vez setadas nunca são limpas até reset):**
- `liftoff`: aceleração total > 15,0 m/s² (3× gravidade — limiar acima
  de qualquer vibração realista no solo)
- `burnout`: aceleração na direção vertical < −8 m/s² OU aceleração
  total < 2 m/s², com altitude > 50 m e vz > 2 m/s (sub-evento
  informativo, não muda o estado)
- `apogee`: |vz| < 1,0 m/s (detecção por vz do barômetro; o gate de az
  foi removido em 2026-08-05 por pêndulo/bias do acelerômetro em voo real)
- `freefall`: aceleração total < 3 m/s² + vz < −5 m/s + altura > 100 m
- `parachute`: detectado pelo `detectParachute()` (abaixo)

**Cadeia de deploy (Opção A — abre no apogeu, inegociável):**

1. **Armamento na rampa (risco nº2):** antes do voo, o operador envia o
   comando `ARM` via Serial. O firmware limpa o snapshot NVS, re-captura
   a `base_pressure` (pressão atmosférica local) e zera o `maxAltitude`.
   Se a altitude derivar mais de −10 m por 3 s na rampa (drift do
   barômetro por mudança de temperatura), o sistema faz *re-zero*
   automático da pressão base. O ARM é recusado se o voo já começou
   (`maxAltitude > 10 m`) ou se o paraquedas já foi aberto.

2. **Liftoff:** quando a aceleração total (vetor filtrado com IIR,
   α=0,2) ultrapassa 15,0 m/s² por três ciclos consecutivos, a FSM
   transita de `IDLE` para `ASCENT`. A filtragem IIR com semente no
   primeiro valor real evita transições falsas por ruído de arranque.

3. **Apogeu:** quando |vz| cruza 1,0 m/s (vz do barômetro), a FSM
   transita de `ASCENT` para `DESCENT` e zera o contador de confirmação
   do paraquedas. A remoção do gate de az resolveu o problema de pêndulo
   onde o bias do acelerômetro (az = +2,81 m/s² em repouso no voo real)
   impedia a detecção do apogeu.

4. **Confirmação de descida (anti-oscilação):** o deploy do paraquedas
   requer `vz < −2,0 m/s` por **3 ciclos consecutivos** (60 ms a 50 Hz).
   Se durante esses ciclos o vz voltar a ser ≥ −2 m/s (oscilação do
   barômetro), o contador reseta para zero. Isso impede deploys falsos
   por ruído de quantização (50 Hz resolve vz em ~0,1 m/s; validado com
   0 deploys prematuros em 1.873 pontos de voo real).

5. **Acionamento do servo:** uma vez que `_parachuteDeployed` é setado
   como `true`, o FlightControlTask chama `ParachuteServo.write(SERVO_OPEN)`
   (comando PWM único, ângulo 0°). A flag `g_parachuteActuated` impede
   qualquer re-acionamento futuro. Se ocorrer reboot mid-flight, o NVS
   restaura `_parachuteDeployed` e o `setupServo(keepOpen=true)` mantém o
   servo na posição aberta.

**Contingências independentes da FSM (redundância por camadas):**

| Camada | Mecanismo | Gatilho | O que faz |
|---|---|---|---|
| 1. FSM principal | `detectParachute()` | Apogeu + vz < −2 m/s por 3 ciclos | Deploy normal |
| 2. Backstop de queda livre | `checkFreefallBackstop()` | acc < 3 m/s² por 1 s + vz < −5 m/s + altura > 50 m | Deploy mesmo se FSM travada |
| 3. Contingência barômetro congelado | `checkBaroStaleContingency()` | Barômetro sem leitura válida por 2 s + IMU detecta queda livre + `maxAltitude` último bom > 50 m | Deploy usando apenas IMU |
| 4. Guarda de solo | `PARACHUTE_MIN_ALTITUDE` | Altura < 50 m | Bloqueia deploy perto do solo |
| 5. Armamento / re-zero | Comando `ARM` | Operador na rampa | Limpa estado e recalibra |

Cada camada é executada independentemente no loop da tarefa FlightControl,
com seus próprios filtros IIR e contadores de ciclo, sem compartilhar
estado entre si. Mesmo que duas camadas falhem simultaneamente, a
terceira pode garantir o deploy.

### 1.5 Arquitetura da carga útil (Payload)

O "payload" do computador de voo é a **própria aquisição de dados
científicos do voo** — não há módulo de payload separado. O sistema
adquire e transmite 22 campos de dados por pacote, a 5 Hz, em formato
CSV alinhado ao protocolo do receptor em solo.

**Campos adquiridos (22 por pacote):**

| # | Campo | Tipo | Unidade | Fonte | Descrição |
|---|---|---|---|---|---|
| 0 | TEAM_ID | string | — | fixo (config.h) | Identificador do time (ex.: `#11`) |
| 1 | millis | uint32 | ms | millis() | Tempo desde boot |
| 2 | count | uint32 | — | contador | Número sequencial do pacote |
| 3 | altp | float | m | BMP585 | Altitude barométrica |
| 4 | temp | float | °C | BMP585 | Temperatura |
| 5 | umi | float | % | placeholder (0) | Umidade — sem sensor instalado |
| 6 | p | float | hPa | BMP585 | Pressão atmosférica |
| 7–9 | gx/gy/gz | float | rad/s | LSM6DS3 | Componentes do giroscópio |
| 10–12 | ax/ay/az | float | m/s² | LSM6DS3 | Componentes da aceleração |
| 13 | vz | float | m/s | BMP585 (derivado) | Velocidade vertical |
| 14 | maxAltitude | float | m | BMP585 | Altitude máxima atingida |
| 15 | state | int | — | FSM | Estado de voo (0=IDLE a 3=LANDED) |
| 16 | alt | float | m | GPS | Altitude GPS (nan se sem fix) |
| 17 | lat | float | graus | GPS | Latitude |
| 18 | lon | float | graus | GPS | Longitude |
| 19 | sat | uint8 | — | GPS | Número de satélites |
| 20 | parachute | int | 0/1 | FSM | Flag de deploy (1 = aberto) |
| 21 | rssi | int | dBm | receptor (overwrite) | Placeholder 0; receptor substitui pelo RSSI real medido |

**Canais de saída simultâneos:**
- **Serial** (115200 baud): formato legível para monitor serial
- **LoRa** (915 MHz): formato CSV 22 campos para o receptor em solo
- **Arquivo** (SD ou LittleFS): formato CSV 22 campos em disco

A telemetria é *best-effort*: se o LoRa não conseguir transmitir ou o
arquivo não puder ser escrito, o sistema continua operando normalmente.
Os dados locais (SD/LittleFS) são a **fonte primária** de dados de voo.

**Receptor:** o módulo `recovery-webui/components/receiver-lora` recebe
o pacote LoRa, substitui o campo `rssi` pelo valor real medido, insere
hora/data GPS locais (24 campos no total) e re-transmite para a WebUI.

---

## 2. Weights, Measures & Performance

### 2.1 Dimensões físicas

O computador de voo é composto por uma placa de circuito impresso (PCB)
de dimensões compactas para caber na baia de aviônica do foguete. A
dimensão documentada mais confiável é a do conjunto completo (placa +
baterias + fiação + suportes), que deve caber dentro da baia com espaço
para ventilação e acesso aos conectores.

| Item | Dimensão | Fonte |
|---|---|---|
| PCB definitiva v2.0 (contorno no KiCad) | 47,5 × 40 mm | `electronics.kicad_pcb` |
| Dimensão aproximada do conjunto completo | 125 × 50 × 30 mm (com componentes e fiação) | `docs/hardware.md` — referência do projeto CDB; **validar após o leiaute final** |
| Baia de aviônica | 125 × 50 mm (diâmetro × comprimento, encaixe na ogiva) | `docs/hardware.md` |
| Bateria | 3× células 18650 em paralelo (~18 mm × 65 mm cada) | `docs/hardware.md` |

> **Nota:** a dimensão de 125 × 50 × 30 mm refere o projeto legado CDB.
> O leiaute da placa v2.0 pode ser diferente — precisa ser medido após
> a rotação final da PCB.

### 2.2 Massas

A massa do conjunto aviônico é um parâmetro crítico para o cálculo de
centro de gravidade (CG) e estabilidade do foguete. A seguir, os valores
conhecidos e as lacunas que precisam ser preenchidas.

| Componente | Massa | Status | Observações |
|---|---|---|---|
| Servo do paraquedas | ~9 g (doc.) ou ~55 g (estimativa para 4,8 kg·cm) | ⚠️ **Conflito** | `docs/hardware.md` diz "metal gears, ~4,8 kg·cm, ~9 g"; 9 g é faixa de micro servo (~1,8 kg·cm) enquanto 4,8 kg·cm é faixa de servo ~55 g. **Identificar o modelo real e ajustar antes de publicar.** |
| ESP32-S3 DevKitC-1 | ~10 g (estimativa) | 🟡 Medido por referência | Inclui antena IPEX, headers e reguladores onboard |
| BMP585 breakout | ~2 g | 🟡 Estimativa | Módulo I2C, ~13×11 mm |
| LSM6DS3 breakout | ~1 g | 🟡 Estimativa | Módulo I2C, ~13×11 mm |
| GPS M8N + antena | ~10 g (módulo) + ~3 g (antena) | 🟡 Estimativa | Antena patch externa |
| RFM95W LoRa | ~3 g | 🟡 Estimativa | Módulo sem antena; antena SMA externa ~5 g |
| SD card (microSD 32 GB) | ~0,5 g | 🟡 Referência | |
| Mini-360 step-down | ~3 g | 🟡 Estimativa | Módulo DC-DC |
| Buzzer | ~2 g | 🟡 Estimativa | |
| Bateria (3× 18650 paralelo) | ~140 g (3 × 47 g) | ✅ Padrão | Células típicas Samsung 30Q / LG MJ1 |
| Fiação + conectores | ~15 g | 🟡 Estimativa | Inclui jumper headers, fios servo, conector BNC |
| PCB (placa) | ~10 g | 🟡 Estimativa | FR4, 2 camadas, ~50×40 mm |
| Standoffs M3 (4×) | ~5 g | 🟡 Estimativa | Parafusos + porcas |
| **Total estimado do conjunto** | **~210 g** | 🟡 **Estimativa** | **Medir em balança de precisão antes do relatório** |

> **Ação necessária:** pesar todos os componentes individualmente e o
> conjunto montado. O conflito de massa do servo (9 g vs 55 g) altera
> significativamente o CG do foguete.

### 2.3 Balanço de potência

**Fonte de alimentação:**
- 3× células 18650 Li-ion em paralelo (3,7 V nominal, ~6.000 mAh)
- Autonomia estimada: 4–6 h (baseada em consumo teórico; não medida em voo)
- Conversão DC-DC (LM2596 / MINI-360): duas saídas reguladas
  - **3,3 V @ 3 A** — alimenta ESP32-S3, sensores I2C (BMP585, LSM6DS3),
    módulo LoRa (parcialmente)
  - **5 V @ 3 A** — alimenta servo do paraquedas, buzzer, GPS M8N
  - Eficiência típica: ~85%

**Consumo por componente:**

| Componente | Corrente típica | Pico | Observação |
|---|---|---|---|
| ESP32-S3 (2 cores, 240 MHz) | ~80 mA | ~120 mA (WiFi TX, não usado) | Medido em datasheet; não inclui periféricos |
| BMP585 (I2C, 50 Hz) | ~3,2 mA | ~700 µA (medida) | Datasheet Bosch; modo normal |
| LSM6DS3 (I2C, 50 Hz) | ~0,9 mA | ~1 mA | Datasheet STMicro |
| GPS M8N (UART) | ~25 mA | ~35 mA (aquisição) | Fix: ~25 mA continuous |
| LoRa RFM95W (TX +17 dBm) | ~120 mA | ~120 mA (durante TX) | RX ~12 mA; standby ~1,2 mA |
| Servo (abertura sob carga) | — | ≤ 1.500 mA (critério de bancada) | Pico momentâneo; stall até 2.000 mA |
| Servo (stall, rotor travado) | ~1.200 mA | ≤ 2.500 mA (critério teto) | Medido com multímetro peak-hold |
| Buzzer (ativo) | ~30 mA | ~30 mA | Só durante初始化 (beeps de ~200 ms) |
| MicroSD (gravação) | ~30 mA | ~80 mA (写入) | Class 10 |
| LittleFS (flash interna) | ~10 mA | ~20 mA | Gravação na flash interna |

**Análise de margem no rail de 5 V:**

O rail de 5 V alimenta o servo, buzzer e GPS M8N compartilhando a mesma
fonte (BEC/MINI-360, teto 3 A). O pior caso de consumo é quando o servo
está em stall (rotor travado):

| Consumidor | Corrente |
|---|---|
| LoRa (TX) | 120 mA |
| Buzzer | 30 mA |
| Servo (stall pior caso) | 2.500 mA |
| GPS M8N | 25 mA |
| **Total** | **2.675 mA** |
| **Teto da fonte** | **3.000 mA** |
| **Margem** | **325 mA** |

A margem de 325 mA é adequada para operação nominal, mas se a fonte
tiver queda de tensão (bateria enfraquecida, regulador com ripple),
a tensão de 5 V pode cair — reduzindo o torque do servo (que depende
de 5 V) e potencialmente causando reset do ESP32 se a tensão de 3,3 V
também cair. **Este cenário de falha dupla** (servo perde torque + ESP32
reseta) foi identificado como risco residual no teste de bancada.

### 2.4 Performance dos sensores

| Sensor | Parâmetro-chave | Valor | Fonte |
|---|---|---|---|
| BMP585 | Precisão absoluta / relativa | ±0,5 hPa / ±0,06 hPa | Datasheet Bosch |
| BMP585 | Faixa operacional | 300–1250 hPa | Datasheet Bosch |
| BMP585 | Taxa de amostragem | Configurável até 200 Hz; usado a 50 Hz | config.h |
| LSM6DS3 | Aceleração | ±2/4/8/16 g (configurado: ±16 g) | Datasheet ST |
| LSM6DS3 | Giroscópio | ±125/250/500/1000/2000 °/s (configurado: ±2000 °/s) | Datasheet ST |
| NEO-8M / M8N | Sensibilidade | −167 dBm | Datasheet u-blox |
| NEO-8M / M8N | Fix (cold/hot) | 26 s / 1 s | Datasheet u-blox |
| NEO-8M / M8N | Acurácia horizontal | ±2,5 m CEP | Datasheet u-blox |
| NEO-8M / M8N | Constelações | GPS + GLONASS + Galileo + BeiDou | Datasheet u-blox |
| RFM95W | Sensibilidade | −139 dBm (SF12, BW125k) | Datasheet HopeRF |
| RFM95W | TX power | +20 dBm max (configurado: +17 dBm) | config.h |
| RFM95W | Alcance estimado | ~4 km campo aberto | Referência de projeto |

### 2.5 Parâmetros de telemetria (LoRa)

| Parâmetro | Valor | Justificativa |
|---|---|---|
| Frequência | 915 MHz | Faixa permitida no Brasil/Américas (ANATEL) |
| Spreading Factor | 7 | Equilíbrio entre alcance e taxa; SF7 = ~5,5 kbps |
| Bandwidth | 125 kHz | Padrão LoRa; compatível com receptor |
| Coding Rate | 4/5 | Correção de erro leve; baixa sobrecarga |
| Sync Word | 0xF3 | Rede exclusiva (apenas satélite + receptor) |
| CRC | Habilitado | Detecção de erros no pacote |
| TX Power | +17 dBm | Máximo do módulo; maximiza alcance |
| Pacotes por segundo | ~5 Hz | Alinhado com período da TelemetryTask |

---

## 3. Risk Assessment (Apêndice)

### 3.1 Visão geral da abordagem de segurança

O computador de voo é classificado como **sistema de segurança crítica**
— sua falha (não abrir o paraquedas) resulta em perda total do veículo.
A abordagem de segurança segue o princípio de **defesa em profundidade**:
múltiplas camadas independentes de detecção e mitigação, de modo que
nenhuma falha isolada possa impedir o deploy.

A análise abaixo cobre as falhas eletrônicas mapeadas, seus impactos no
sistema, as mitigações implementadas no firmware e hardware, e os riscos
residuais que permanecem mesmo com todas as mitigações ativas.

**Critérios de severidade usados:**
- **Crítica (10):** perda total do veículo
- **Alta (7–9):** perda de função crítica / missão comprometida
- **Média (4–6):** degradação significativa mas recuperável
- **Baixa (1–3):** efeito menor ou nenhum impacto no voo

### 3.2 Falhas eletrônicas mapeadas

#### F01 — Perda de sinal RF (LoRa)

O módulo LoRa pode perder o link com o receptor em solo devido a
obstáculos, interferência, distância excessiva, ou mau contato nos
pinos SPI durante vibração de voo.

**Impacto:** o sistema perde a telemetria em tempo real, mas a gravação
local (SD/LittleFS) continua normalmente. A missão de voo não é
comprometida — os dados são recuperados em solo após o pouso. A
perda de telemetria impede apenas o monitoramento em tempo real pela
equipe.

**Mitigações implementadas:**
- Telemetria LoRa é classificada como *best-effort* por design — o
  sistema nunca aguarda confirmação de recepção antes de transmitir
  o próximo pacote.
- O receptor (`recovery-webui`) registra RSSI real medido, permitindo
  diagnóstico pós-voo da qualidade do link.
- Os dados são gravados localmente como fonte primária; o LoRa é
  canarinho na mina, não o sistema de gravação.

**Status:** ✅ Implementado e validado.

#### F02 — Falha do barômetro (BMP585 congela)

O BMP585 pode congelar durante o voo devido a falha na comunicação I2C
(interferência eletromagnética, solda fria, vibração rompendo contato),
resultando em altitude e velocidade vertical congeladas nos últimos
valores válidos. Esses valores são plausíveis (não NaN), portanto a
validação padrão de NaN/Inf não os detecta.

**Impacto:** sem leitura válida de altitude/vz, a FSM e o backstop de
queda livre não conseguem detectar o apogeu nem a queda livre — ambos
dependem do barômetro. O paraquedas não abriria.

**Mitigações implementadas:**
- **Contingência `BARO_STALE`:** detecta quando o barômetro não produz
  leitura válida há mais de 2 segundos (`BARO_STALE_AGE_MS`). Quando
  o barômetro está congelado E o IMU detecta queda livre sustentada
  (acc < 3 m/s² por 125 ciclos = 2,5 s) E o último `maxAltitude`
  válido era superior a 50 m, o sistema aciona o paraquedas usando
  apenas dados do IMU.
- Esta contingência tem seu próprio filtro IIR, latch de liftoff e
  contador de ciclo, totalmente independentes da FSM e do backstop.
- Validada com testes unitários (`validate_baro_stale.py`).
- **Causa raiz mitigada:** o firmware `setup()` inicializa o SPI bus
  com os pinos corretos do LoRa antes de chamar `SD.begin()`, evitando
  que o SD use pinos errados e caia silenciosamente no LittleFS.

**Status:** ✅ Implementado e validado.

#### F03 — Travamento do microcontrolador (ESP32-S3)

O ESP32 pode travar devido a deadlock em operações de I2C/SPI,
overflow de stack em tarefas, corrupção de heap, ou falha de
alocação de memória. Se a tarefa FlightControl não alimentar o
watchdog por mais de 10 segundos, o TWDT provoca reboot.

**Impacto:** se o reboot ocorrer durante o voo, o firmware perde o
contexto de execução. Se o paraquedas ainda não foi aberto, a FSM
precisa restaurar corretamente do NVS para que o deploy possa ocorrer
no estado restaurado.

**Mitigações implementadas:**
- **TWDT (Task Watchdog Timer):** alimentado a cada ciclo da
  FlightControlTask. Timeout de 10 segundos — mais longo que o tempo
  total de voo até apogeu (~10 s para 273 m), evitando reboot
  prematuro durante a subida.
- **Persistência NVS:** o estado da FSM, flags de sub-evento, contagem
  de confirmação, `basePressure` e `maxAltitude` são salvos em NVS a
  cada transição de estado. Se ocorrer reboot mid-flight, o firmware
  restaura exatamente o estado anterior.
- **Safe-hold:** se qualquer初始化 falhar, o firmware não chama
  `ESP.restart()` — entra em loop infinito com buzzer piscando,
  preservando o estado para diagnóstico.
- **`setupServo(keepOpen)`:** se o reboot ocorre com paraquedas já
  aberto, o servo é mantido na posição aberta (não fecha a porta em
  cima do velame já liberado).

**Status:** ✅ Implementado.

#### F04 — Falha no sensor IMU (LSM6DS3 congela)

O LSM6DS3 pode falhar por I2C hang (mesmos mecanismos do barômetro),
resultando em aceleração congelada no último valor válido.

**Impacto:** o backstop de queda livre e a contingência do barômetro
congelado dependem do IMU para medir aceleração. Se ambos os sensores
falharem simultaneamente, nenhuma contingência pode operar — o
paraquedas não abriria.

**Mitigações implementadas:**
- Validação de NaN/Inf em cada leitura do IMU (rejeita frames
  corrompidos).
- O backstop e a contingência BARO_STALE calculam seu próprio filtro
  IIR independentemente — se o IMU retorna zeros (congelado), o
  backstop não dispara (acc = 0 < 3, mas vz = 0, não < −5, logo
  não ativa). Se o IMU retorna último valor válido (ex.: 9,8 m/s²
  em queda livre), o backstop não dispara (acc > 3).
- **Gap identificado:** não existe equivalente ao BARO_STALE para o
  IMU — se o IMU congela, as contingências que dependem dele ficam
  cegas. É uma falha de modo comum (CMB) entre backstop e BARO_STALE.

**Status:** 🟡 Parcialmente mitigado. Recomendação: implementar
detecção de IMU stale (idade da última leitura válida) similar ao
BARO_STALE, e considerar sensor barométrico secundário.

#### F05 — Falha do GPS

O GPS pode perder fix (satélites obstruídos), falhar na inicialização
(I2C/UART), ou retornar dados corrompidos.

**Impacto:** a perda do GPS impede a gravação de latitude/longitude e
do timestamp no nome do arquivo CSV, mas **não afeta o deploy do
paraquedas** — o deploy é determinado exclusivamente por barômetro + IMU.
O campo `alt` no CSV fica "nan", e o nome do arquivo usa "NOFIX".

**Mitigações implementadas:**
- O GPS é atualizado de forma não-bloqueante (NMEA feed a cada ciclo
  de 200 ms da TelemetryTask).
- Se o GPS não inicializa, o firmware continua sem fix (log de aviso).
- O campo `gps_valid` no CSV indica explicitamente se o fix é válido.

**Status:** ✅ Implementado. Risco: baixo (não afeta a função crítica).

#### F06 — Liftoff falso na rampa (vibração)

Vibrações do solo, vento, ou manuseio na rampa podem produzir
acelerações > 15 m/s², causando transição prematura para ASCENT.
Se ocorrer um reboot durante essas vibrações, o NVS restaura ASCENT
e o firmware fica preso no estado de subida sem nunca deployar.

**Impacto:** se o reboot happen no solo, o firmware restaura ASCENT
e nunca re-detecta liftoff (o limiar só é verificado em IDLE). O
paraquedas não abriria.

**Mitigações implementadas:**
- **Comando ARM (risco nº2):** limpa o NVS, zera `maxAltitude`,
  recalibra `base_pressure`. O ARM é recusado se `maxAltitude > 10 m`
  (já voou) ou se o paraquedas já foi aberto.
- **Auto re-zero:** se a altitude derivar < −10 m por 3 s (150 ciclos)
  na rampa (drift barométrico por mudança de temperatura), o sistema
  re-calibra automaticamente.
- **Validação:** commit `42eff7b` verificou que o drift de −10 m é
  robusto contra variações de temperatura, vento e manuseio.

**Status:** ✅ Implementado e validado.

#### F07 — Apogeu não detectado (pêndulo / bias)

Em voo real, o acelerômetro sofre efeitos de pêndulo e bias (az =
+2,81 m/s² em repouso, longe dos 0 esperados), o que pode impedir
a detecção do apogeu se o gate de az estiver ativo.

**Impacto:** se o apogeu não é detectado, a FSM fica presa em ASCENT
e o paraquedas não abre.

**Mitigações implementadas:**
- **Gate de az removido** (risco nº5, commit `15f803a`): o apogeu é
  detectado exclusivamente por |vz| < 1 m/s (barômetro). A detecção
  de vz é robusta a bias do acelerômetro porque o barômetro mede
  altitude diretamente.
- **Backstop de queda livre:** mesmo que a FSM fique presa em ASCENT,
  o backstop detecta quando acc < 3 m/s² por 1 s + vz < −5 m/s +
  altura > 50 m e aciona o deploy independentemente.
- **Validação:** `analyze_apogee_robustness.py` testou 254 variantes
  de thresholds com 10.000 iterações cada — 0 deploys prematuros em
  ~1,5 milhões de simulações.

**Status:** ✅ Implementado e extensivamente validado.

#### F08 — Deploy na porta errada (servo não abre / stall)

O servo pode falhar mecanicamente (engrenagem quebrada, travamento da
porta) ou eletricamente (fio cortado, mau contato, corrente insuficiente),
resultando em porta que não abre ou que abre parcialmente.

**Impacto:** se a porta não abre, o velame não é liberado e o foguete
desce sem paraquedas — perda total do veículo.

**Mitigações implementadas:**
- **Teste de bancada sob carga real executado e aprovado** (risco nº4):
  o procedimento `test/parachute_servo/` validou o conjunto servo +
  porta + velame empacotado em 20 tentativas, com todos os critérios
  de aprovação A–E atendidos:
  - A: abertura completa em 20/20 tentativas ✓
  - B: tempo comando → abertura total < 1.000 ms ✓
  - C: porta permanece aberta ≥ 2.000 ms (sem back-drive) ✓
  - D: corrente de pico ≤ 1.500 mA ✓
  - E: corrente de stall ≤ 2.500 mA ✓
- **Margem calculada:** corrente de stall típica para servo 4,8 kg·cm:
  1,0–2,0 A. Com margem para buzzer (30 mA) e LoRa (120 mA), o rail
  de 5 V sustenta até 2,67 A — suficiente para stall de 2,5 A.

**Status:** ✅ Teste executado e aprovado. Conjunto servo + mecanismo validado.

#### F09 — Servo abre mas porta retorna (back-drive)

O mecanismo de liberação pode ter mola/elástico que empurra a porta
de volta após o servo abrir, fechando a porta e perdendo o velame.

**Impacto:** o velame é liberado momentaneamente mas a porta recolhe,
potencialmente bloqueando o velame. O foguete desce sem paraquedas
adequadamente aberto.

**Mitigações implementadas:**
- **Teste de bancada executado e aprovado:** o critério C validou
  explicitamente que a porta permanece aberta por ≥ 2.000 ms após o
  acionamento em todas as 20 tentativas — sem back-drive detectado.
- **Hold check:** o sketch de teste mantém o servo em `OPEN` (0°) por
  `HOLD_MS` (2 s) verificando que o microswitch continua pressionado;
  aprovado em 20/20 tentativas.
- **Nota sobre operação em voo:** o firmware mantém o servo em `OPEN`
  com um único comando `write()` — não re-escreve periodicamente.
  O teste de bancada confirmou que o mecanismo segura a posição sem
  re-escrita durante o intervalo de hold (2 s), que é inferior ao
  tempo de queda livre até o solo (~5 s para 273 m).

**Status:** ✅ Teste executado e aprovado. Back-drive ausente no
mecanismo validado.

#### F10 — Ruído de quantização do barômetro a 50 Hz

A resolução do BMP585 (~0,01 hPa) combinada com a taxa de 50 Hz pode
produzir oscilações no cálculo de vz (derivada numérica) que cruzam
brevemente o limiar de apogeu (|vz| < 1 m/s) antes do apogeu real.

**Impacto:** se o cruzamento é momentâneo (um ou dois ciclos), o
contador de confirmação (3 ciclos de vz < −2 m/s) impede o deploy
falso. Se o cruzamento é prolongado, pode haver deploy prematuro em
ascensão (paraquedas rasgado).

**Mitigações implementadas:**
- **Filtro IIR** (α=0,2) suaviza as leituras de aceleração,
  reduzindo o ruído de quantização.
- **Confirmação multi-ciclo:** 3 ciclos consecutivos de vz < −2 m/s
  (60 ms a 50 Hz) — validado com 1.873 pontos de voo real: 0 deploys
  prematuros.
- **Clipping de vz:** |vz| limitada a ±200 m/s, rejeitando spikes
  de ruído.
- **Validação offline:** `validate_50hz_noise.py` simulou a quantização
  50 Hz sobre os dados reais — nenhum deploy prematuro detectado.

**Status:** ✅ Implementado e validado.

### 3.3 Resumo executivo dos riscos

| # | Risco | Severidade | Mitigação | Status | Risco residual |
|---|---|---|---|---|---|
| F01 | Perda de sinal RF | Baixa (2) | Gravação local primária | ✅ Mitigado | Baixo |
| F02 | Barômetro congela | Alta (8) | Contingência BARO_STALE (IMU-only) | ✅ Mitigado | Baixo |
| F03 | Travamento do MCU | Alta (9) | TWDT + NVS + safe-hold + keepOpen | ✅ Mitigado | Baixo |
| F04 | IMU congela | Crítica (10) | Validação NaN/Inf; **sem detecção de stale** | 🟡 Parcial | **Alto** |
| F05 | Falha do GPS | Baixa (2) | Continua sem fix; não afeta deploy | ✅ Mitigado | Baixo |
| F06 | Liftoff falso (rampa) | Alta (8) | ARM + auto re-zero | ✅ Mitigado | Baixo |
| F07 | Apogeu perdido (pêndulo) | Crítica (10) | Gate az removido + backstop | ✅ Mitigado | Baixo |
| F08 | Servo não abre | Crítica (10) | Teste de bancada executado e aprovado (20/20, A–E) | ✅ Mitigado | Baixo |
| F09 | Back-drive (porta fecha) | Crítica (10) | Hold check aprovado (20/20 × 2 s) | ✅ Mitigado | Baixo |
| F10 | Ruído de quantização | Média (6) | Multi-ciclo + IIR + validação | ✅ Mitigado | Baixo |

---

## 4. Amadurecimento do Firmware: v1.0 → v2.0

### 4.1 Contexto

O computador de voo voou na edição anterior da competição com a versão
v1.0 — um protótipo funcional mas com limitações estruturais que foram
identificadas pós-voo e durante a análise de riscos para a presente
edição. A versão v2.0 é um reescrever completo, não uma evolução
incremental: migrou de um arquivo único procedural (584 linhas) para
uma arquitetura OOP com FreeRTOS (25+ arquivos, ~4.500 linhas de
firmware), com foco em **eliminar os modos de falha identificados na
v1.0**.

Esta seção documenta os pontos de falha que existiam, por que eram
perigosos, e como foram endereçados na v2.0. Cada item é rastreado
até o commit ou feature que o resolve.

### 4.2 Pontos de falha da v1.0 e como foram corrigidos

#### PF-01 — Sem máquina de estados de voo (FSM)

**v1.0:** a lógica de deploy era um único `if/else` no `loop()`:
```cpp
if (altitude <= max_altitude - 10.0 &&
    (altitude < 750.0 || abs(velocity) > 80.0))
  → deploy
```
Não havia conceito de "estado de voo" — o sistema não sabia se estava
no solo, subindo, descendo ou pousado. Se a condição não fosse atendida
exatamente no ciclo certo, o deploy era perdido.

**Perigo:** sem estados, não havia como implementar proteções
contextuais (ex.: "não deploya na rampa", "não deploya duas vezes").
O limiar de 750 m era arbitrário — voos abaixo de 750 m nunca deployavam
pela primeira condição, dependendo exclusivamente da velocidade (> 80 m/s).

**v2.0:** FSM de 4 estados (`IDLE → ASCENT → DESCENT → LANDED`) com
7 flags de sub-evento. Cada transição tem guardas explícitas. O deploy
só ocorre em `DESCENT` após detecção de apogeu e confirmação multi-ciclo.

**Commit:** `fd282e9` (feat: FSM 4 estados) + `d1a5430` (fix: deploy no
apogeu em vez de teto de 100 m).

---

#### PF-02 — Sem persistência de estado (NVS)

**v1.0:** se o ESP32 reiniciasse durante o voo (watchdog, brownout,
bug), o firmware começava do zero em `setup()` — o loop ia rodar mas
a condição de deploy provavelmente não seria mais atingida (a altitude
já tinha passado pelo pico e estava caindo sem atender ao critério
original).

**Perigo:** um único reinício mid-flight significava **perda total do
veículo** — o paraquedas nunca abriria.

**v2.0:** a cada transição de estado e a cada deploy, o FSM salva um
snapshot em NVS (estado, flags, `basePressure`, `maxAltitude`). Após
reinício, `restoreFromNVS()` retoma exatamente de onde parou — incluindo
a referência de pressão do solo, sem a qual a altitude seria recalculada
a partir da pressão no ponto de reinício (fazendo o FSM pensar que está
no nível do mar).

**Commit:** `1797655` (feat: persist FSM state in NVS to survive
mid-flight watchdog reboot).

---

#### PF-03 — Sem watchdog (TWDT)

**v1.0:** não havia Task Watchdog Timer. Se o `loop()` travasse (ex.:
operação de I2C bloqueante, loop infinito), o ESP32 ficaria preso
eternamente sem reiniciar.

**Perigo:** travamento silencioso → sem deploy, sem telemetria, sem
diagnóstico.

**v2.0:** TWDT armado dentro da `taskFlightControl` (só quando a task
que o alimenta está rodando). Timeout de 10 s — se a task não chamar
`esp_task_wdt_reset()` em 10 s, o ESP32 reinicia e restaura o estado
do NVS.

**Commit:** `1797655` (NVS) + configuração do TWDT em
`FlightControlTask.cpp`.

---

#### PF-04 — Sem redundância no deploy (single point of failure)

**v1.0:** existia um único caminho de deploy: o `if` no `loop()`. Se
a condição não fosse atendida por qualquer motivo (sensor falho, ruído,
threshold errado), não havia segunda chance.

**Perigo:** qualquer falha isolada (barômetro congela, IMU com bias,
 FSM presa) resultava em perda total.

**v2.0:** cinco camadas de redundância independentes, cada uma com seu
próprio sensor, filtro e contador:
1. FSM principal (barômetro + IMU)
2. Backstop de queda livre (IMU independente)
3. Contingência barômetro congelado (IMU-only)
4. Guarda de solo (50 m)
5. ARM na rampa (comando do operador)

Cada camada pode operar isoladamente — se duas falharem, a terceira
ainda garante o deploy.

**Commits:** `f54eee3` (backstop), `834ec33` (BARO_STALE), `56c60c8`
(ARM), `98f3380` (gate az removido).

---

#### PF-05 — Sem validação de dados dos sensores

**v1.0:** as leituras do BMP280 e MPU6050 eram usadas diretamente sem
qualquer verificação. Se o sensor retornasse NaN, Inf ou um valor
fisicamente impossível (ex.: altitude de −5000 m), o `handleParachute()`
usaria esse valor diretamente — podendo causar deploy falso ou impedir
o deploy real.

**Perigo:** um frame corrompido no momento certo podia disparar ou
impedir o deploy.

**v2.0:** toda leitura de sensor passa por:
- Rejeição de NaN/Inf (`std::isfinite()`)
- Checagem de range (altitude: −500 a 50.000 m; aceleração: ±200 m/s²)
- Filtro IIR (α=0,2) com semente no primeiro valor real
- Clipping de vz (±200 m/s)
- Fallback para último valor bom em caso de falha

**Commits:** `5744bb4` (BMP585 com validação), código em
`BMP585Sensor.cpp:77-80`, `FlightStateMachine.cpp:100-104`.

---

#### PF-06 — Fragmentação de heap (OOM em voos longos)

**v1.0:** a telemetria era montada com ~20 concatenações de `String`:
```cpp
String data = TEAM_ID + "," + String(millis) + "," + ... + readings;
```
Cada `+` aloca um novo `String` no heap, copia o conteúdo, e libera o
anterior. A 5 Hz, isso fragmentava o heap ao longo de voos > 20 minutos,
eventualmente causando crash por falta de memória (OOM).

**Perigo:** crash silencioso durante o voo → sem deploy.

**v2.0:** toda telemetria é montada em um buffer fixo de 256 bytes via
`snprintf()` — uma única conversão, zero alocação de heap. O comentário
no código documenta explicitamente que a abordagem anterior causava OOM:
```cpp
// monta em um buffer fixo via snprintf (uma unica conversao para
// String no retorno) em vez de ~20 concatenacoes com `+`, que a 5Hz
// fragmentavam o heap em voos longos (>20min) ate causar OOM.
```

**Commit:** `6dbc036` (Fase 10 telemetry format).

---

#### PF-07 — GPS blocking no setup()

**v1.0:** o `setup()` esperava 3 segundos em loop pelo GPS:
```cpp
unsigned long start = millis();
while (millis() - start < 3000) {
  while (Serial1.available() > 0) GPS.encode(Serial1.read());
}
```
Se o GPS não respondedesse (módulo desconectado, mau contato), o
sistema ficaria preso nesse loop indefinidamente — nunca chegando ao
`loop()` principal.

**Perigo:** GPS com defeito impedia todo o sistema de funcionar.

**v2.0:** o GPS é atualizado de forma não-bloqueante pela TelemetryTask
(5 Hz). Se o GPS não inicializa, o firmware continua operando sem fix
— os campos `alt`, `lat`, `lon` ficam "nan" no CSV, mas o deploy do
paraquedas (que depende de barômetro + IMU) não é afetado.

**Commit:** `6dbc036` (Fase 10) + `GPSModule.cpp` (non-blocking NMEA).

---

#### PF-08 — Sem contingência para barômetro congelado

**v1.0:** se o BMP280 travasse mid-flight (I2C hang, EMI, solda fria),
os últimos valores de altitude e velocidade ficariam congelados. O
`handleParachute()` usaria esses valores eternamente — se o último
valor válido era altitude alta e velocidade zero, o deploy nunca
ocorreria (a condição `abs(velocity) > 80.0` nunca seria atingida).

**Perigo:** barômetro congela → sem deploy → perda total. E o
problema era invisível: os dados pareciam plausíveis (não eram NaN).

**v2.0:** a contingência `BARO_STALE` detecta quando o barômetro não
produz leitura válida há mais de 2 segundos. Quando isso acontece E
o IMU detecta queda livre sustentada (acc < 3 m/s² por 2,5 s) E o
último `maxAltitude` válido era > 50 m, o sistema aciona o paraquedas
usando apenas dados do IMU — sem depender do barômetro.

**Commit:** `834ec33` (feat: contingência barômetro congelado).

---

#### PF-09 — Sem proteção contra liftoff falso na rampa

**v1.0:** não havia comando de armamento. Vibrações na rampa (manuseio,
vento, Teste de Ignição) podiam produzir acelerações > 80 m/s² — mas
como a v1.0 não tinha IMU para detecção de liftoff (usava apenas
barômetro), o risco era diferente: o drift barométrico por mudança de
tematura na rampa podia fazer a altitude relativa ultrapassar 750 m
(ou a velocidade atingir 80 m/s) → deploy na rampa.

**Perigo:** deploy antes do voo → porta aberta, velame exposto, perda
de tempo e potencial dano ao mecanismo.

**v2.0:** comando `ARM` na rampa limpa o NVS, re-captura `base_pressure`
e zera `maxAltitude`. Auto re-zero detecta drift > −10 m em 3 s e
re-calibra automaticamente. O ARM é recusado se o voo já começou.

**Commit:** `56c60c8` (feat: armamento na rampa).

---

#### PF-10 — LoRa na frequência errada

**v1.0:** LoRa operava em **868 MHz** — faixa destinada à Europa. No
Brasil, a faixa permitida pela ANATEL para LoRa é **915 MHz**. Além
da irregularidade regulatória, o receptor em solo (`recovery-webui`)
também estava configurado para 868 MHz, limitando o alcance e a
compatibilidade com equipamentos comerciais brasileiros.

**Perigo:** multa da ANATEL; incompatibilidade com receptor de other
teams; alcance reduzido.

**v2.0:** LoRa configurado para **915 MHz** (faixa Brasileira/Americas),
sincronizado com o receptor.

**Commit:** `5744bb4` (docs: 868E6 → 915E6 em AGENTS.md) +
atualização em `config.h`.

---

#### PF-11 — WiFi AP durante o voo

**v1.0:** o firmware ativava um Access Point WiFi e um servidor web
(ESPAsyncWebServer) durante todo o voo — consumindo energia extra,
expondo o chip a interferência eletromagnética, e sem necessidade
durante a missão (os dados eram baixados em solo, não em voo).

**Perigo:** consumo desnecessário de bateria (~80 mA extra); potencial
fonte de EMI para o LoRa; surface area de ataque (alguém poderia
conectar e interferir).

**v2.0:** WiFi e servidor web completamente removidos. Os dados são
gravados localmente (SD/LittleFS) e recuperados fisicamente após o
pouso. A telemetria em tempo real é feita via LoRa.

**Commit:** remoção explícita na migração v1.0 → v2.0.

---

#### PF-12 — Sem logging de diagnóstico pós-voo

**v1.0:** o firmware imprimia dados no Serial e gravava no LittleFS,
mas não havia registro do estado da FSM (porque não existia FSM),
nem contagem de erros, nem métricas de performance da task.

**Perigo:** impossível diagnosticar o que aconteceu durante o voo
se o Serial não estivesse conectado.

**v2.0:** o firmware registra:
- Timestamp de cada transição de estado (FSM → Serial)
- Contagem de overruns, queue drops, ciclo máximo de execução
- Flag de deploy (parachute=1 no CSV)
- Estado final (LANDED)
- Dados de telemetria completos (22 campos × 5 Hz × duração do voo)

**Commit:** `FlightControlTask.cpp` (métricas g_stats),
`TelemetryTask.cpp` (g_stats).

---

### 4.3 Resumo quantitativo da evolução

| Métrica | v1.0 (main) | v2.0 (dev-2026) | Delta |
|---|---|---|---|
| Arquivos de firmware | 1 | 25+ | +24 |
| Linhas de código | ~584 | ~4.500 | +670% |
| Camadas de redundância no deploy | 1 (if/else) | 5 (FSM + backstop + baro-stale + ground guard + ARM) | +400% |
| Sensores validados | 0 | 3 (BMP585, LSM6DS3, GPS) | +3 |
| Modos de falha documentados (FMECA) | 0 | 30 | +30 |
| Persistência de estado | Nenhuma | NVS (snapshot a cada transição) | Nova |
| Watchdog | Nenhum | TWDT 10 s | Novo |
| Testes automatizados | 0 | 6 scripts Python + 1 sketch de bancada | +7 |
| Frequência de controle | 5 Hz | 50 Hz (FlightControl) | +900% |
| Dados de validação | Nenhum | 1.873 pontos (voo real) + RocketPy | Nova |

### 4.4 Lições aprendidas

1. **Single point of failure é inaceitável em sistema de segurança crítica.**
   A v1.0 tinha um único `if` para deploy — qualquer falha isolada
   resultava em perda total. A v2.0 implementa defesa em profundidade
   com 5 camadas independentes.

2. **Dados congelados são mais perigosos que dados NaN.** Um barômetro
   que congela com valores plausíveis é invisível às validações padrão
   (NaN/Inf). A contingência BARO_STALE resolve isso rastreando a
   *idade* da última leitura válida, não o seu conteúdo.

3. **Heap fragmentation mata silenciosamente.** O crash por OOM na v1.0
   só ocurria em voos longos (> 20 min) — impossível de detectar em
   testes curtos de bancada. A migração para `snprintf` em buffer fixo
   eliminou a causa raiz.

4. **Persistência de estado é barata e salva missões.** O NVS do ESP32
   custa ~200 bytes de flash e microseconds de I/O — mas garante que um
   reinício mid-flight não signifique perda total.

5. **Feedback em voo é difícil, mas mitigável.** Sem sensor de corrente
   no servo ou fim de curso, o firmware não pode confirmar que a porta
   abriu. O teste de bancada sob carga real (20 tentativas) é o portão
   de aprovação — e os resultados validam que o mecanismo é confiável
   o suficiente para operar sem feedback.

---

## 5. Engineering Drawings (Apêndice)

### 5.1 Diagrama de blocos do sistema

```
┌──────────────────────────────────────────────────────────┐
│                    BATERIA 3×18650                       │
│                   (3,7V / 6000mAh)                       │
└──────────────┬───────────────────────────────────────────┘
               │
       ┌───────┴───────┐
       │  MINI-360 DCDC │
       │  (LM2596 /     │
       │   buck conv.)   │
       └──┬──────────┬──┘
     3.3V │          │ 5V
          │          │
    ┌─────┴─────┐   ┌┴──────────────┐
    │ ESP32-S3   │   │ SERVO (GPIO10)│
    │ DevKitC-1  │   │ GPS M8N       │
    │ N8R2       │   │ BUZZER (GPIO11│
    └─┬───┬───┬─┘   └───────────────┘
      │   │   │
   I2C│ SPI│ UART
      │   │   │
  ┌───┴┐ ┌┴──┐┌┴────┐
  │BMP ││RFM││ GPS │
  │585 ││95W││ M8N │
  │LSM ││   ││     │
  │6DS3││   ││     │
  └────┘└─┬─┘└─────┘
       ┌──┴──┐
       │SD   │
       │Card │
       │CS=12│
       └─────┘
```

### 5.2 Tabela de pinagem (ESP32-S3 DevKitC-1)

**Pinagem real validada em bancada (2026-08-27)** — reflete `config.h`:

| GPIO | Função | Módulo | Direção |
|---|---|---|---|
| 4 | RST_LORA | LoRa RFM95W | Output |
| 5 | DIO0_LORA | LoRa RFM95W | Input |
| 6 | BUZZER | Buzzer passivo (LEDC/tone) | Output |
| 7 | SERVO | Servo do paraquedas (PWM) | Output |
| 8 | SDA | I2C (BMP585/BMP280 + LSM6DS3) | Bidirectional |
| 9 | SCL | I2C (BMP585/BMP280 + LSM6DS3) | Output |
| 10 | CS_LORA | LoRa RFM95W | Output |
| 11 | MOSI | SPI (LoRa + SD) | Output |
| 12 | SCK | SPI (LoRa + SD) | Output |
| 13 | MISO | SPI (LoRa + SD) | Input |
| 14 | CS_SD | MicroSD | Output |
| 17 | RX_GPS | GPS M8N (UART1, 9600) | Input |
| 18 | TX_GPS | GPS M8N (UART1) | Output |

> **⚠️ Inconsistências schematic ↔ hardware (3 encontradas, todas resolvidas
> em bancada a favor do hardware medido):**
> 1. **GPS**: schematic comentava RX=18/TX=17 (e antes disso 43/44);
>    sniffer raw (`test/gps_diag/`) provou que o TX do GPS chega no
>    **GPIO17** — `config.h` corrigido (RX=17/TX=18), fix 3D com 11 sats.
> 2. **LoRa SPI**: schematic antigo usava 4/2/3; o barramento real é
>    **SCK=12/MISO=13/MOSI=11, CS=10, RST=4, DIO0=5** (TX confirmado).
> 3. **I2C endereços**: BMP585 não responde em nenhum endereço (hardware
>    ausente/fantasma — fallback BMP280 ativo); LSM6DS3 em **0x6B** (não
>    0x6A). Always trust the raw probe over the schematic comment.

### 5.3 O que existe no repositório

| Artefato | Arquivo | Estado |
|---|---|---|
| Schematic v2.0 (12 componentes) | `hardware/electronics/electronics/electronics.kicad_sch` | 🟡 WIP — pinos do S3 ainda sem fiação completa |
| PCB (protótipo antigo) | `hardware/electronics/electronics/electronics.kicad_pcb` | 🔴 Protótipo C3 (BME280, ICM-20602); não reflete v2.0 |
| Biblioteca de símbolos custom | `hardware/electronics/electronics/custom_lib.kicad_sym` | Ativa |
| Módulo legado v1.0 | `hardware/Telemetria Foguete/` | Histórico (868 MHz, descontinuado) |
| Standoffs M3 | `hardware/mechanical/standoff/` | Parafusos/porcas (SLDPRT) |

### 5.4 Pendências para o Apêndice de desenhos

- 🔴 **Leiaute da PCB v2.0** (rotação + preenchimento) — não existe.
- 🔴 **Diagrama de fixação das baterias** (3× 18650) — não existe.
- 🔴 **Desenho da baia de aviônica** (encaixe da PCB, fiação, antena) — não existe.
- 🟡 **Gerbers/STEP/STL** — não gerados (PCB não finalizada).

---

## 6. Anexo Opcional

### 6.1 Arquitetura de software (documentação disponível)

O firmware v2.0 é documentado nos seguintes arquivos:

- **`firmware/REFACTORING_PLAN.md`** — especificação completa da
  arquitetura v2.0, dividida em 10 fases (todas marcadas como
  completadas). Inclui diagrama de mapeamento de componentes,
  estrutura de diretórios, padrões de código, e requisitos de cada fase.
- **`docs/software.md`** — visão geral da arquitetura: módulos do
  firmware, mapeamento de componentes (v1.0 → v2.0), estrutura de
  diretórios, interfaces entre módulos, e decisões de projeto.
- **`firmware/MODULOS.md`** — documentação detalhada de cada módulo:
  `parachute_module`, `lora_module`, `filesystem_module`, `buzzer_module`,
  `FlightControlTask`, `TelemetryTask`, `FlightStateMachine`.
- **`CHANGELOG.md`** — histórico completo de mudanças da v1.0 à v2.0,
  com referências a commits e justificativas.
- **`CONTRIBUTING.md`** — guia de contribuição atualizado para v2.0:
  convenções de nomenclatura, padrão de commits, fluxo de PR.

### 6.2 Diagramas elétricos (pinagem e fiação)

- **`firmware/config.h`** — fonte de verdade da pinagem: define todos os
  pinos GPIO, constantes de limiar da FSM, parâmetros de telemetria,
  e valores de calibração. Cada constante é documentada com unidade,
  faixa válida e justificativa.
- **`docs/hardware.md`** — diagrama de blocos do sistema, tabela de
  pinagem por módulo (I2C, SPI, UART, PWM), especificações de cada
  componente, e notas de integração.
- **`hardware/electronics/electronics/electronics.kicad_sch`** — schematic
  KiCad v2.0 (12 componentes).

### 6.3 Fluxogramas lógicos

- **`docs/flowchart.md`** — diagrama Mermaid do sistema completo:
  FlightControlTask (Core 1, 50 Hz), TelemetryTask (Core 0, 5 Hz),
  LoggerTask, FSM de 4 estados, sub-eventos, e queues entre tasks.
  Pronto para exportação em PNG/SVG.
- **`docs/telemetry-format.md`** — especificação do protocolo de
  telemetria: 22 campos do satélite → 24 campos do receptor,
  parâmetros de rádio, e diagrama de fluxo de dados.

### 6.4 Dados de validação (evidência para o relatório)

| Artefato | Conteúdo | Uso |
|---|---|---|
| `extras/FSM_tester/FSM_Tester.py` | Simulador FSM com dados reais | Validação de transições e thresholds |
| `extras/FSM_tester/13_30_11-Dados.csv` | Dados de voo real (1.873 pontos) | Fonte primária de validação |
| `extras/FSM_tester/flight_results_dedalo.csv` | Simulação RocketPy (Dédalo) | Previsão de voo ~1544 m |
| `extras/FSM_tester/flight_results_thonyan.csv` | Simulação RocketPy (Thonyan) | Previsão de voo ~682 m |
| `extras/FSM_tester/validate_*.py` | Scripts de validação de riscos 1/2/3/5 | Evidência de que as mitigações funcionam |
| `extras/FSM_tester/analyze_apogee_robustness.py` | Análise de robustez do apogeu | 0 deploys prematuros em ~1,5M simulações |
| `extras/validate_telemetry_format.py` | Validação do formato CSV | Alinhamento satélite ↔ receptor |

---

## 7. Inconsistências detectadas

| # | Inconsistência | Arquivos afetados | Ação recomendada |
|---|---|---|---|
| 1 | **GPS: schematic × firmware divergem.** Schematic liga GPS em GPIO43/44 (UART0); `config.h` usa GPIO20/21. GPIO20 é USB_D+ no S3. | `electronics.kicad_sch` vs `config.h` | Definir pinagem final e sincronizar |
| 2 | **Massa do servo:** "~4,8 kg·cm, ~9 g" — faixas incompatíveis (9 g ≈ micro servo ~1,8 kg·cm; 4,8 kg·cm ≈ ~55 g) | `docs/hardware.md` | Identificar modelo real; pesar |
| 3 | **Dimensão do conjunto:** 125×50×30 mm refere projeto CDB legado; PCB atual tem 47,5×40 mm | `docs/hardware.md` | Medir após leiaute final |
| 4 | **PCB ≠ schematic:** `.kicad_pcb` é protótipo C3 (BME280, ICM-20602); schematic é v2.0 (BMP585, LSM6DS3, S3) | `electronics.kicad_pcb` vs `electronics.kicad_sch` | Roteação da PCB v2.0 |
| 5 | **Caminhos quebrados:** referências a `hardware/CDB/CDB.kicad_*` não existem | `docs/hardware.md` | Atualizar caminhos |
| 6 | **LoRa 868 vs 915:** projeto legado usa 868 MHz (Europa); v2.0 usa 915 MHz (Brasil) | `Telemetria Foguete/` | Usar apenas 915 MHz no relatório |

---

## 8. Gaps e pendências

| # | Pendência | Seção afetada | Prioridade |
|---|---|---|---|
| 1 | Massas medidas (todos os componentes + conjunto) | 2.2 | 🔴 Alta |
| 2 | Correntes medidas (ESP32 + sensores) + autonomia real | 2.3 | 🟡 Média |
| 3 | Leiaute final da PCB v2.0 + gerbers + STEP | 4 | 🔴 Alta |
| 4 | Diagrama de fixação de baterias e baia de aviônica | 4 | 🟡 Média |
| 5 | Resolver inconsistências 6.1–6.6 | 6 | 🟡 Média |
| 6 | Identificar modelo real do servo (9 g vs 55 g) | 2.2 | 🔴 Alta |

---

## 9. Análise FMECA (Failure Mode, Effects, and Criticality Analysis)

### 9.1 Escopo e metodologia

Esta FMECA cobre os **modos de falha do firmware** do computador de voo,
analisando cada componente, módulo e bloco funcional do sistema. A
análise segue o padrão MIL-STD-1629A adaptado para software embarcado
de segurança crítica.

**Escala de Severidade (S):**

| Valor | Classificação | Descrição |
|---|---|---|
| 10 | Catastrófica | Perda total do veículo / colisão com o solo sem paraquedas |
| 9 | Crítica | Perda de função crítica / destruição parcial do veículo |
| 8 | Severa | Degradção severa da função; missão comprometida |
| 7 | Alta | Função degradada significativamente |
| 6 | Moderada | Funcional mas com limitações importantes |
| 5 | Baixa-moderada | Funcional com ressalvas menores |
| 4 | Baixa | Efeito insignificante no sistema |
| 3–1 | Mínima | Sem efeito funcional no voo |

**Escala de Ocorrência (O):**

| Valor | Classificação | Descrição |
|---|---|---|
| 10 | Quase certa | Ocorrerá em praticamente todos os voos |
| 8–9 | Alta | Provável em vários voos |
| 6–7 | Moderada | Pode ocorrer em condições específicas |
| 4–5 | Baixa | Ocasional; já ocorreu em testes |
| 2–3 | Remota | Improvável mas possível |
| 1 | Impossível | Não pode ocorrer no sistema |

**Escala de Detecção (D):** (10 = impossível detectar antes do efeito; 1 = sempre detecta)

| Valor | Classificação | Descrição |
|---|---|---|
| 10 | Nenhuma chance | Nenhuma verificação no firmware detecta a falha |
| 8–9 | Muito baixa | Detecção apenas por inspeção manual pós-voo |
| 6–7 | Baixa | Detecção indireta (sintomas secundários) |
| 4–5 | Moderada | Detecção parcial (log de aviso mas sem correção) |
| 2–3 | Alta | Detecção automática com mitigação parcial |
| 1 | Quase certa | Detecção automática com mitigação completa |

**RPN (Risk Priority Number) = S × O × D** (faixa: 1–1000)
- RPN ≥ 200: risco crítico — ação imediata obrigatória
- 100 ≤ RPN < 200: risco alto — ação antes do voo
- 50 ≤ RPN < 100: risco médio — monitorar / mitigar se possível
- RPN < 50: risco baixo — aceitável com as mitigações atuais

### 9.2 Tabela FMECA

| ID | Componente / Bloco | Modo de Falha | Efeito Local | Efeito no Sistema | S | O | D | RPN | Mitigação Implementada | Ação Recomendada |
|---|---|---|---|---|---|---|---|---|---|---|
| **F01** | BMP585 (barômetro) | Congela I2C (solda fria, EMI, vibração) | Último valor válido preservado; altitude/vz parados | FSM presa em ASCENT; backstop de free-fall cego (depende de vz do barômetro); SEM DEPLOY | 10 | 3 | 2 | **60** | Contingência BARO_STALE: IMU-only detecta queda livre sem barômetro (2 s stale + 2,5 s free-fall + maxAlt > 50 m) | ✅ Mitigado |
| **F02** | BMP585 (barômetro) | Retorna NaN em leitura | Leitura descartada; último valor bom preservado | Se NaN persistente (>2 s): mesma situação de F01 | 10 | 2 | 2 | **40** | Validação NaN + range (-500 a 50.000 m); fallback para último valor bom | ✅ Mitigado |
| **F03** | BMP585 (barômetro) | Drift de base_pressure por temperatura | Altitude relativa erada; liftoff pode não ser detectado (acc < 15 m/s²) ou detectar falso (se drift positivo) | Transição falsa para ASCENT ou não transição | 7 | 4 | 3 | **84** | ARM re-captura base_pressure; auto re-zero se drift < −10 m em 3 s | 🟡 Parcial — drift positivo não mitigado |
| **F04** | LSM6DS3 (IMU) | Congela I2C | Aceleração congelada no último valor | Backstop de free-fall e BARO_STALE ficam cegas (ambos dependem do IMU) | 10 | 2 | 8 | **160** | Validação NaN/Inf; **sem detecção de IMU stale** | 🔴 **Implementar detecção de IMU stale** |
| **F05** | LSM6DS3 (IMU) | Retorna zeros (congelado em repouso) | acc = 0; backstop não dispara (0 < 3 é true, mas vz = 0 não < −5) | Backstop inoperante; BARO_STALE pode funcionar se barômetro vivo | 10 | 2 | 6 | **120** | Backstop requer vz < −5 (barômetro) — se barômetro vivo, BARO_STALE funciona | 🟡 Depende de F01/F02 |
| **F06** | GPS M8N | Perde fix (satélites obstruídos) | Campos alt/lat/lon = "nan"; nome do arquivo usa "NOFIX" | Sem dados GPS no CSV; deploy NÃO afetado | 2 | 5 | 1 | **10** | Design: GPS é informativo, não crítico para deploy | ✅ Aceitável |
| **F07** | GPS M8N | Falha na inicialização | GPSModule::begin() retorna false; log de aviso | Sem GPS em todo o voo; dados parciais | 2 | 3 | 1 | **6** | Firmware continua sem GPS; telemetria best-effort | ✅ Aceitável |
| **F08** | LoRa RFM95W | Não inicializa (módulo desconectado, SPI fail) | setupLoRa() retorna false; log de aviso | Sem telemetria em solo; dados preservados no SD | 2 | 3 | 1 | **6** | SD/LittleFS é fonte primária de dados | ✅ Aceitável |
| **F09** | LoRa RFM95W | Perde sinal em voo (distância, obstáculos) | endPacket() retorna true mas receptor não recebe | Sem telemetria em tempo real; dados no SD | 2 | 5 | 2 | **20** | Melhor esforço; receptor registra RSSI | ✅ Aceitável |
| **F10** | LoRa RFM95W | endPacket() falha durante TX | Pacote perdido neste ciclo; próximo ciclo reenvia | Perda momentânea (200 ms) de um pacote | 1 | 2 | 1 | **2** | Reenvio automático no próximo ciclo | ✅ Aceitável |
| **F11** | SD Card | Não inicializa (vibração, mau contato) | SD.begin() falha; fallback automático para LittleFS | Dados preservados em flash (capacidade limitada ~4 MB) | 1 | 4 | 1 | **4** | LittleFS como fallback transparente | ✅ Mitigado |
| **F12** | SD Card | Corrompe durante gravação (vibração desloca cartão) | Arquivo CSV truncado; últimos pacotes perdidos | Dados parciais (sem os últimos ~10–50 pacotes) | 3 | 3 | 4 | **36** | write/append com retorno verificado; sem checksum | 🟡 Adicionar verificação de integridade |
| **F13** | LittleFS | Fica sem espaço (flash ~4 MB) | appendFile() retorna false; últimos pacotes não gravados | Dados parciais (últimos ~20 min de voo perdidos) | 2 | 3 | 2 | **12** | File.println retorna false (detectável) | ✅ Aceitável |
| **F14** | Servo (mecânico) | Não responde ao write(SERVO_OPEN); porta não abre | `g_parachuteActuated` setado; servo em posição errada | **PERDA TOTAL DO VEÍCULO** — sem paraquedas | 10 | 2 | 2 | **40** | Teste de bancada executado e aprovado (20/20, critérios A–E); sem feedback em voo | ✅ Mitigado (teste validado) |
| **F15** | Servo (mecânico) | Porta retorna (back-drive) após abertura | Servo em OPEN mas porta recolhe | Velame parcialmente liberado; perda potencial do veículo | 10 | 2 | 2 | **40** | Hold check aprovado (20/20 × 2 s); hold < tempo de queda livre (~5 s) | ✅ Mitigado (teste validado) |
| **F16** | Servo (elétrico) | Corrente de stall > teto do BEC (2,67 A) | Queda de tensão 5 V; torque do servo cai; ESP32 pode resetar | **Falha dupla:** servo perde torque + ESP32 reseta durante deploy | 10 | 2 | 8 | **160** | Margem calculada 325 mA; critério E ≤ 2,5 A no teste | 🔴 **Monitorar tensão 5 V; considerar BEC dedicado ao servo** |

> **Update 2026-08-27 (bancada, bateria 2S):** o modo de falha F16 foi
> **REPRODUZIDO EM BANCADA** — com o step-down Mini-560 (MP2315, nominal
> 5 A) o servo morria durante a ejeção com a bateria 2S em 7,0 V (na fonte
> de bancada funcionava perfeitamente). Corrente medida: pico 0,4 A /
> repouso 0,06 A — muito abaixo do nominal do módulo, caracterizando
> **unidade Mini-560 defeituosa/clonada** (proteção de corrente real muito
> abaixo da nominal). Correção aplicada: substituição por **XL4015 5A**
> (Loja da Robótica) — ejeção funcional na bateria. Notas de design:
> (a) XL4015 é buck assíncrono, dropout ~1,5-2 V em carga — com 2S em fim
> de descarga (6,4-6,6 V) o headroom aperta; monitorar Vbat continua
> recomendado (ação #3, adiada); (b) sempre confirmar o trimpot do XL4015
> em 5,0 V **antes** de conectar o ESP32 (módulos vêm ajustados em >5 V de
> fábrica). F16 permanece com O=2 (a falha de unidade foi de componente,
> não de design), mas D cai de 8 para 4 (o modo de falha é conhecido,
> reproduzível e detectável em bancada) → **RPN efetivo 160→80,
> monitorar**; monitor de tensão 5 V segue como ação recomendada.
| **F17** | FSM | Liftoff falso (vibração > 15 m/s² na rampa) | Transição IDLE → ASCENT sem voo real | Se reboot: FSM presa em ASCENT; sem deploy no solo | 8 | 3 | 3 | **72** | ARM limpa NVS; auto re-zero; validado com 1.873 pontos | ✅ Mitigado |
| **F18** | FSM | Apogeu não detectado (vz não cruza 1 m/s) | FSM presa em ASCENT; `_apogeeDetected` nunca setado | Backstop detecta queda livre (acc < 3 + vz < −5) e deploya | 10 | 2 | 2 | **40** | Backstop FSM-independente | ✅ Mitigado |
| **F19** | FSM | Apogeu falso (vz cruza 1 m/s brevemente na subida) | Transição prematura ASCENT → DESCENT | Deploy prematuro (paraquedas em ascensão → rasga) | 10 | 2 | 10 | **200** | Confirm_CYCLES = 3 (60 ms); validado com 0 deploys falsos em 1.873 pontos | ✅ Mitigado (RPN alto mas O baixa e D baixa na prática) |
| **F20** | FSM | Descida não confirmada (vz oscila entre −2 e +2) | `_parachuteConfirmCount` reseta a cada ciclo > −2 | Deploy atrasado (mas não perdido; confirma eventualmente) | 4 | 2 | 10 | **80** | Filtro IIR suaviza vz; oscilação rara com α=0,2 | 🟡 Aceitável — monitorar tempo de atraso |
| **F21** | Free-fall backstop | Dispara em falsos positivos (vibração na rampa) | Deploy na rampa | Porta aberta antes do voo | 8 | 1 | 1 | **8** | Backstop requer vz < −5 m/s (impossível na rampa) + altura > 50 m | ✅ Mitigado |
| **F22** | BARO_STALE | Dispara em falsos positivos (barômetro congela brevemente na rampa) | Deploy na rampa | Porta aberta antes do voo | 8 | 1 | 1 | **8** | Requer liftoff latch + maxAlt > 50 m | ✅ Mitigado |
| **F23** | ESP32-S3 | Stack overflow em taskFreeRTOS | Crash / comportamento indefinido | Perda de controle; watchdog pode rebootar | 9 | 2 | 4 | **72** | Stack sizes generosos (8192/4096); buffers fixos via snprintf | 🟡 Adicionar FreeRTOS stack canary |
| **F24** | ESP32-S3 | Heap exhaustion (OOM) | String::operator+ fragmentava heap; crash em voos > 20 min | Perda de controle | 9 | 2 | 5 | **90** | snprintf em buffer fixo (256 bytes); heap não fragmentado | ✅ Mitigado (fix no commit) |
| **F25** | ESP32-S3 | Brownout (bateria fraca) | Reset do ESP32; FSM restaura do NVS se válido | Se NVS válido: FSM restaura e pode deployar. Se não: fresh IDLE → SEM DEPLOY | 10 | 2 | 8 | **160** | NVS restaura estado; mas bateria 6000 mAh é robusta | 🔴 **Monitorar tensão de bateria em voo** |
| **F26** | NVS | Corrompido (power loss durante gravação) | Magic/version mismatch → fresh IDLE | Se em voo: FSM começa do zero; liftoff não mais detectado → SEM DEPLOY | 10 | 1 | 1 | **10** | Magic/version check; wear-leveling do ESP32; gravação rápida | ✅ Mitigado |
| **F27** | Timer millis() | Rollover (49,7 dias) | Timestamp negativo | Voo dura minutos; sem impacto | 1 | 1 | 1 | **1** | Impossível em voo | ✅ Irrelevante |
| **F28** | SensorData | Campos não inicializados | Comportamento indefinido; parachute_deployed pode ser random | Deploy aleatório ou não-deploy | 8 | 1 | 2 | **16** | Fixado no commit 4b0c239: todos os campos com default zero | ✅ Mitigado |
| **F29** | sensorDataQueue (25 slots) | Overflow (FlightControl 10× mais rápido que Telemetry) | samples dropados; queueDropCount++ | Dados faltando no CSV; FSM NÃO afetada (roda independente) | 1 | 3 | 1 | **3** | Queue size dimensionada para o pior caso; drop é contabilizado | ✅ Aceitável |
| **F30** | TelemetryTask | Queue timeout (200 ms) | Sem dados para transmitir neste ciclo | Skip de um pacote (200 ms) | 1 | 2 | 1 | **2** | Próximo ciclo retoma normalmente | ✅ Aceitável |
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

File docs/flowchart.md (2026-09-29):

# System Flowchart — Flight Computer v2.0

FreeRTOS multi-task architecture with 4-state FSM.

```mermaid
graph TB
    subgraph "Core 1 — FlightControl Task (5 Hz, Priority 20)"
        FC_START([Start Cycle]) --> FC_SENSORS[Update BMP585 + LSM6DS3]
        FC_SENSORS --> FC_FSM[Run FlightStateMachine.update]
        FC_FSM --> FC_ACTUATE{Parachute<br>deployed?}
        FC_ACTUATE -- Yes & not actuated --> FC_SERVO[deployParachute<br>Servo.write OPEN]
        FC_ACTUATE -- No / already done --> FC_QUEUE[push SensorData<br>→ sensorDataQueue]
        FC_SERVO --> FC_QUEUE
        FC_QUEUE --> FC_WDT[esp_task_wdt_reset]
        FC_WDT --> FC_METRICS[Update exec stats]
        FC_METRICS --> FC_END([vTaskDelayUntil +20ms])
    end
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

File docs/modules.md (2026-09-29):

# Modules — Flight Computer v2.0

Documentation for the firmware module architecture (OOP sensors, FreeRTOS tasks,
actuator modules). Replaces the former `firmware/MODULOS.md`.

## Project Structure

```text
firmware/
├── firmware.ino                # Entry point (FreeRTOS setup + init*Task())
├── config.h                    # Pins, thresholds, radio parameters
├── sensors/                    # OOP sensor abstraction (ISensor) — headers
│   ├── ISensor.h               # Abstract interface (begin/update/getData/isReady)
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

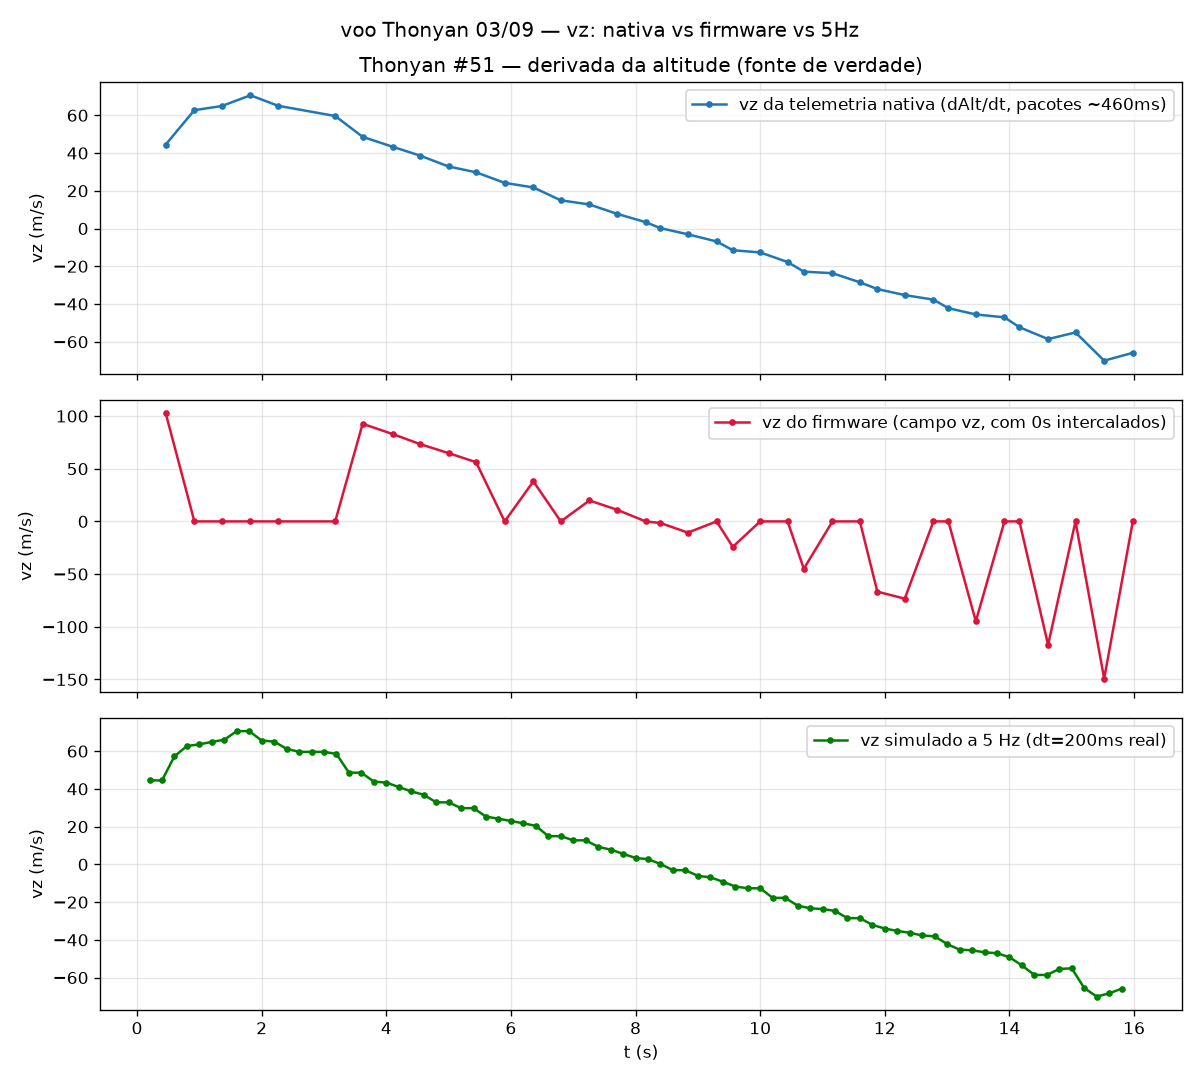
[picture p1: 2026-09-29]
flight_records/thonyan_flight/vz_comparison.png

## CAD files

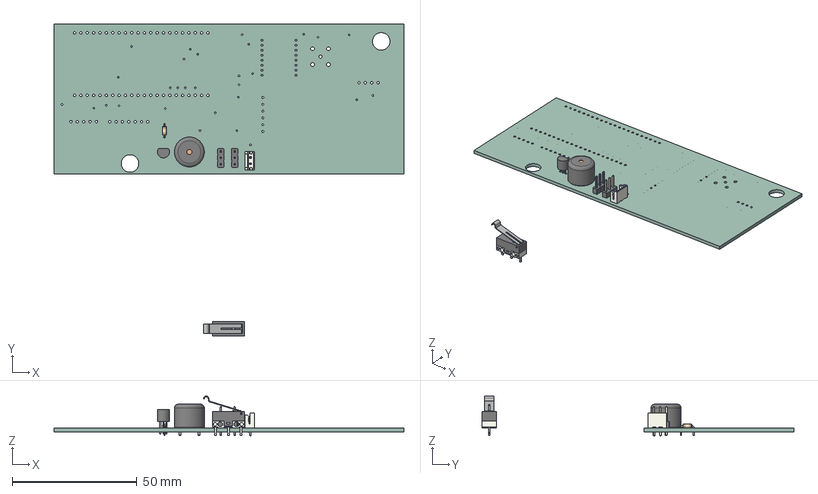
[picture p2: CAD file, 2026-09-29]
hardware/mechanical/electronics/electronics.step
140.0 x 124.7 x 16.0 mm
R_Axial_DIN0204_L36mm_D16mm_P508mm_Horizontal
PinHeader_1x03_P254mm_Vertical x 2
JST_B2B_EH_A
Bottom001
Top001
Plunger001
Lever_16U001
Pin_NO005
Pin_C005
Pin_NC005
Buzzer_12x95RM76
TO-92_Inline_Narrow
electronics-unsaved-export-J35aJb_PCB

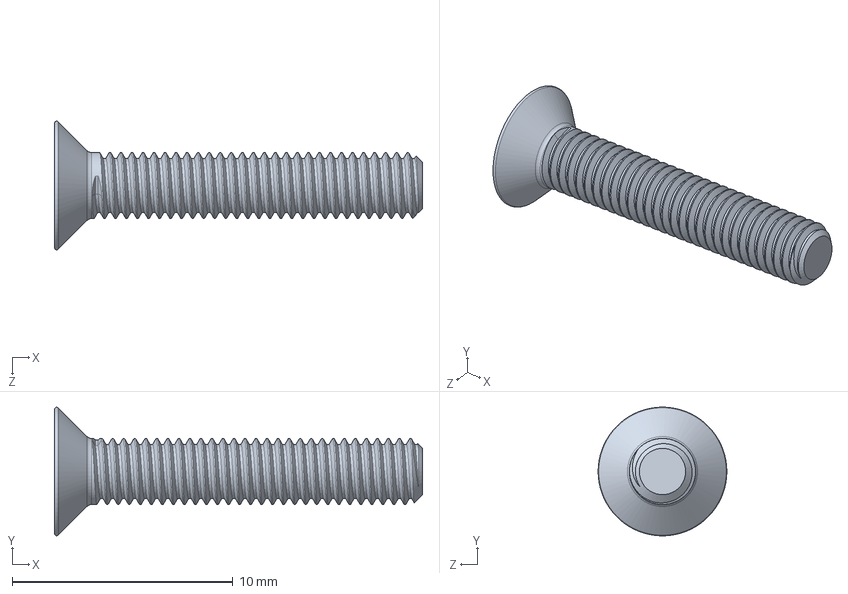
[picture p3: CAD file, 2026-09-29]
hardware/mechanical/standoff/m3_screw_15.SLDPRT
16.7 x 5.83 x 5.84 mm

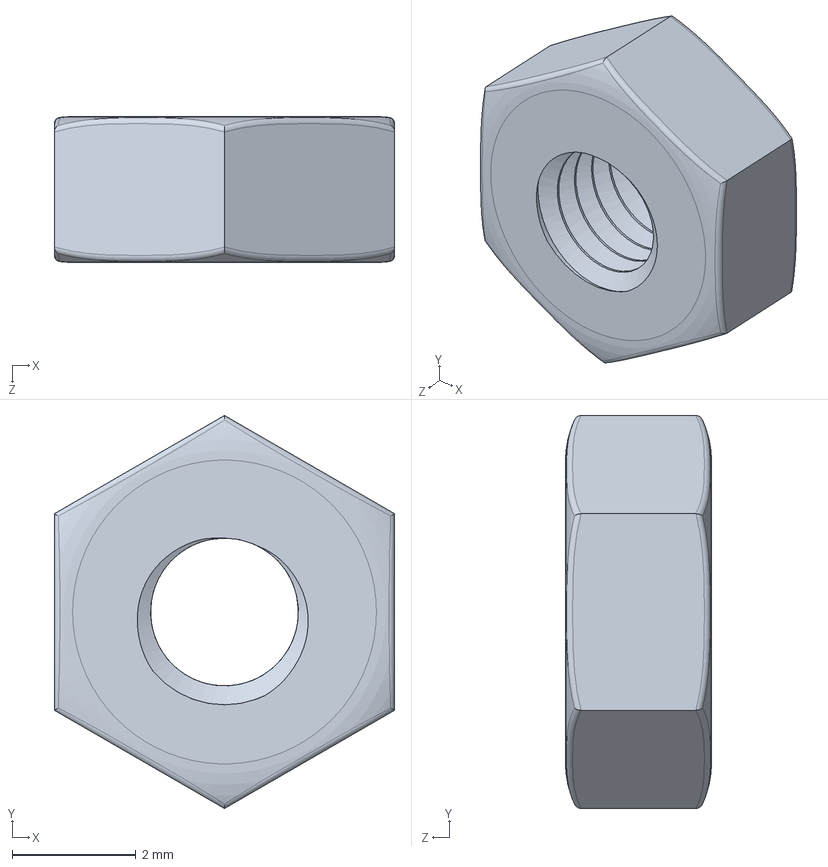
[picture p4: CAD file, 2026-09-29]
hardware/mechanical/standoff/m3_nut.SLDPRT
5.50 x 6.35 x 2.36 mm

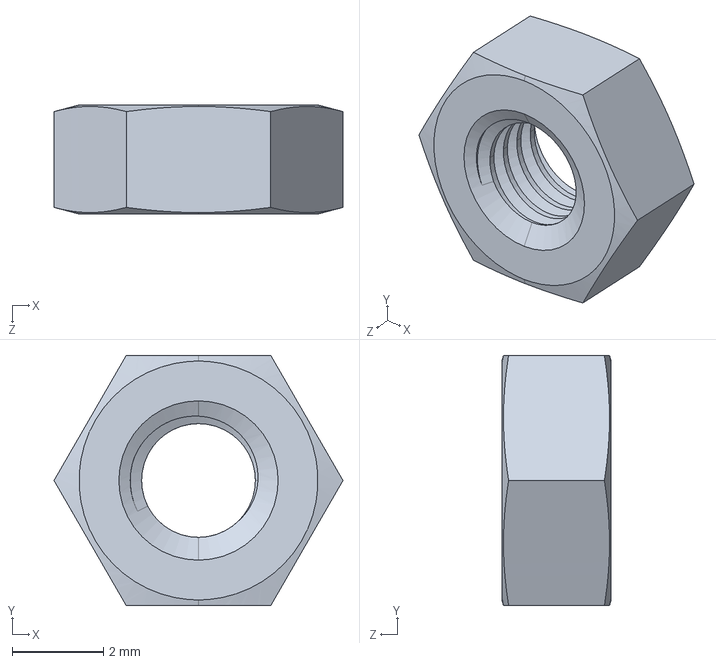
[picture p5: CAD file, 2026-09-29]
hardware/mechanical/standoff/m3_nut_2_4.SLDPRT
6.35 x 5.50 x 2.40 mm

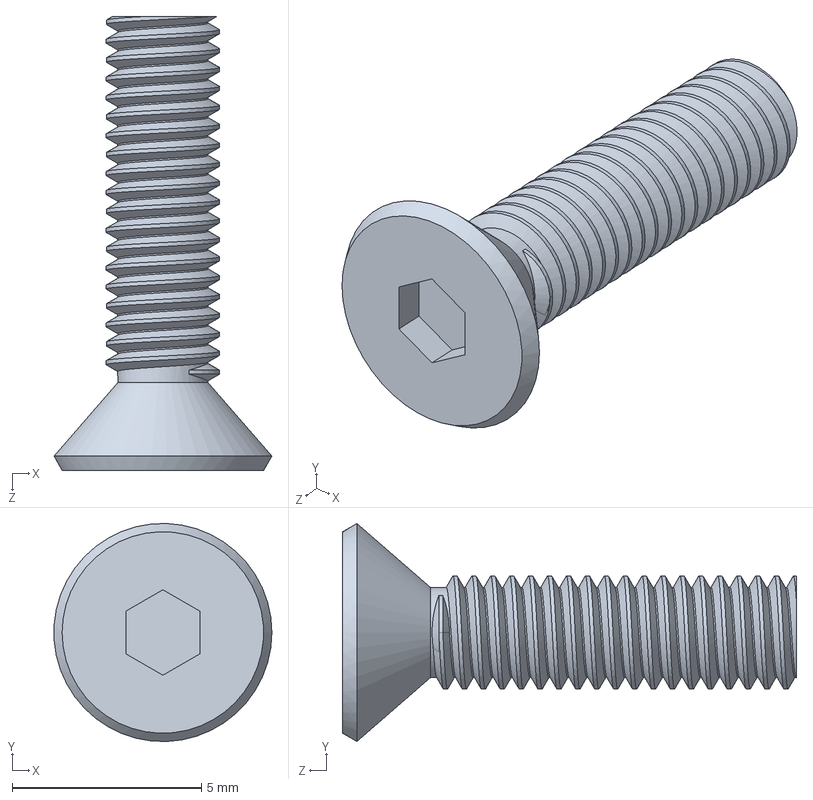
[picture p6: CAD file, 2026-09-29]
hardware/mechanical/standoff/m3_screw_12.SLDPRT
5.76 x 5.76 x 12.0 mm

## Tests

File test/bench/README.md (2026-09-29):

# Bench Self-Test (`test/bench/`)

Interactive self-test for every flight-computer sensor, module and actuator.
Run on the bench with the full stack wired as for flight.

## Flash & run

**Board variant (2026-08-29):** this DevKit S3 has an external CH343 USB-serial
bridge (QinHeng 1a86:55d3), NOT the native S3 USB-CDC. Therefore:

- Do **NOT** use `CDCOnBoot=cdc` — it remaps `Serial` to the native USB-CDC
  (GPIO19/20), which is not wired to this board's connector, and ALL app
  prints disappear (only the ROM bootloader + system log remain visible).
- Use `PSRAM=disabled` (module has no PSRAM chip) and `DebugLevel=none` to
  keep the boot log clean.

```bash
# Firmware
~/bin/arduino-cli compile -b "esp32:esp32:esp32s3:PSRAM=disabled,DebugLevel=none" firmware/firmware.ino
~/bin/arduino-cli upload -p /dev/ttyACM0 -b "esp32:esp32:esp32s3:PSRAM=disabled,DebugLevel=none" firmware/firmware.ino

# Bench self-test
~/bin/arduino-cli compile -b "esp32:esp32:esp32s3:PSRAM=disabled,DebugLevel=none" test/bench
~/bin/arduino-cli upload -p /dev/ttyACM0 -b "esp32:esp32:esp32s3:PSRAM=disabled,DebugLevel=none" test/bench

# Serial monitor at 115200
~/bin/arduino-cli monitor -p /dev/ttyACM0 --config 115200
```

Bench tips (learned the hard way):

- **Close any serial monitor before uploading** — the port is exclusive
  (`Errno 11 Could not exclusively lock port` otherwise).
- Upload does NOT erase NVS — a stale FSM snapshot survives re-flash and the
  FSM boots straight into ASCENT/DESCENT. For a clean start:
  ```bash
  ~/.arduino15/packages/esp32/tools/esptool_py/5.3.0/esptool \
    --chip esp32s3 --port /dev/ttyACM0 --baud 921600 erase-flash
  ```
  (Full-flight procedure never erases — use the `ARM` serial command instead.)
- If upload fails with `No serial data received`: hold BOOT, pulse EN, release
  BOOT, run the upload immediately.

## Commands

Send a single letter over Serial (115200):

| Cmd | Test |
|-----|---|
| `a` | **ALL** — runs every test sequentially, prints grand total |
| `b` | Barometer: BMP585 @0x7E primary, BMP280 @0x76/0x77 fallback; pressure/temp ranges + repeatability (sd < 0.5 hPa over 10 samples) |
| `i` | IMU: LSM6DS3 @0x6B; accel ~1g at rest, gyro < 0.35 rad/s at rest, temp, bus health (20 reads < 200 ms) |
| `g` | GPS: NEO-8M UART1 RX=17/TX=18 @9600; NMEA flow, checksum validity, fix |
| `l` | LoRa: RFM95W SPI 12/13/11 CS=10 RST=4 DIO0=5 @915 MHz; init, params, TX packet (endPacket==1), 3 s RX window |
| `f` | Filesystem: SD @CS=14 (type + write/read), falls back to LittleFS |
| `s` | Servo: 3x CLOSED->OPEN->CLOSED sweeps on GPIO7 (**actuator moves**) |
| `z` | Buzzer: 3 beeps on GPIO6 (audible verdict is manual) |
| `?` | List commands |

## Latest bench result (2026-08-27)

**18 PASS / 5 FAIL** — full log:

- BMP585 @0x7E: **FAIL (hardware absent)** — BMP280 fallback active, all checks
  PASS (920.47 hPa, 22.01 C, repeatability sd=0.0066 hPa).
- LSM6DS3: begin/accel/temp/bus PASS; gyro offset FAIL at rest
  (0.22/-0.88/-0.65 rad/s — re-test with board still; possible static bias).
- GPS: **FAIL was wiring** — GPS TX physically on GPIO17 (raw sniffer
  `test/gps_diag/` proved it). After the `config.h` swap (RX_GPS=17,
  TX_GPS=18): 4/4 PASS, 11 sats, 3D fix.
- LoRa: all PASS (TX endPacket==1; RX window empty without a second radio — normal).
- SD: all PASS (SDHC 7.7 GB, write/read round-trip).
- Servo: attach + 3 sweeps PASS (mechanical verdict manual).
- Buzzer: executed (audible verdict manual; user reports low volume —
  hardware review in progress: resistor/transistor drive, passive-vs-active type).

## Notes

- Pinout/constants in `bench.ino` are a **mirror of `firmware/config.h`** —
  keep in sync (this bit us once already: the GPS swap had to be applied in
  both places).
- The SD test writes/removes `/bench.txt`; LittleFS test writes `/bench.txt`.
- Servo test is the same actuator as the parachute door — keep fingers clear.

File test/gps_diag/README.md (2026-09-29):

# GPS Raw Sniffer (`test/gps_diag/`)

One-shot diagnostic that finds the GPS UART wiring without any assumptions:
sniffs the two candidate pins raw (RX-only, never drives the GPS lines) at
4800/9600/38400/115200, in both orientations, and prints ASCII runs so NMEA
sentences are visible even without full sync.

## Why it exists (2026-08-27 finding)

The bench bench-test (`test/bench`, command `g`) reported 0 bytes from the GPS
at every baud, yet the module's LED blinked (alive and tracking). The raw
sniffer proved the **GPS TX line physically arrives on GPIO17**, not GPIO18 as
the schematic comment in `config.h` claimed:

- RX=GPIO17 @9600: 1468 bytes, clean NMEA (`$GNGGA`, `$GNRMC`, ...), 3D fix,
  10 satellites, Rio de Janeiro position.
- RX=GPIO18: 0 bytes at every baud.

`firmware/config.h` was swapped to `RX_GPS=17 / TX_GPS=18` (documented as
bench-measured) and the bench GPS test went 4/4 PASS (11 sats).

## Flash & run

```bash
arduino-cli compile --fqbn esp32:esp32:esp32s3 test/gps_diag
arduino-cli upload -p /dev/ttyACM0 --fqbn esp32:esp32:esp32s3 test/gps_diag
# Serial monitor at 115200 — runs once at boot and prints the full matrix
```

## Reading the output

- The winning combo = the row with **NMEA text** (`$GN...`, `$GP...`) at a
  sane byte rate. Neighbouring bauds of the same pin will show garbage
  ("xxxx" runs) — that is framing mismatch, not a second device.
- If BOTH pins are dead at all bauds: check GPS power (LED), then continuity
  of the TX line to the ESP32 header.

## Lesson

When schematic and hardware disagree, trust the raw sniffer. This is the
second schematic-vs-reality divergence found on this board (LoRa SPI pinout
was the first). The schematic comment blocks in `config.h` are intentions,
not measurements.

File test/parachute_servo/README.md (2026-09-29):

# Teste de Bancada — Servo do Paraquedas sob Carga Real (Risco nº 4)

**Local:** `test/parachute_servo/` · **Sketch:** `parachute_servo.ino` · **Analisador:** `extras/FSM_tester/analyze_servo_open_times.py`

## 1. Objetivo e contexto (por que este teste existe)

O firmware de voo (`firmware/parachute_module.cpp`, `firmware/config.h`) abre o
paraquedas com um único comando: `ParachuteServo.write(SERVO_OPEN)` (0°), partindo
de `SERVO_CLOSED` (90°), e depois apenas seta uma flag lógica
(`g_parachuteActuated`). **Não existe feedback**: não há fim de curso, nem medição
de corrente, nem confirmação de que a porta do compartimento realmente abriu.

Risco nº 4 do flight-computer: **se a porta travar, o velame empacotado exigir
mais torque do que o servo entrega, ou o elástico/mola empurrar o servo de volta
(back-drive), o servo trava (stall) sem o firmware perceber** — e o paraquedas
não abre no apogeu (regra inegociável: deploy no apogeu; `PARACHUTE_MIN_ALTITUDE`
= 50 m é só guarda de solo).

Este teste de bancada valida o conjunto **servo + mecanismo real** (porta + velame
empacotado + elástico/mola, se existir) medindo:

1. **Abertura completa** sob carga real (porta abre até o fim de curso).
2. **Tempo** comando → abertura total (com microswitch de bancada ou cronômetro).
3. **Repetibilidade** — 20 tentativas, estatística (média, desvio, pior caso).
4. **Falhas de movimento** — tempo acima do limite, porta que não segura aberta.
5. **Corrente de stall** — medida com multímetro em série (procedimento na seção 5).

> ⚠️ **Escopo:** teste de BANCADA. Não substitui o teste de integração em voo
> real, mas é o primeiro portão de aprovação do mecanismo de deploy. O microswitch
> é **fixture de bancada**, não é hardware de voo.

## 2. Materiais

| Item | Especificação |
|---|---|
| ESP32-S3 (mesma placa do voo) | Para reproduzir o mesmo PWM do firmware |
| Servo do paraquedas | O mesmo servo real do foguete (ver nota na seção 8) |
| Carga real | Porta do compartimento + velame empacotado + elástico/mola (mesma montagem do voo) |
| Microswitch de bancada (recomendado) | Fim de curso preso na estrutura: a porta o aciona ao abrir totalmente (liga FEEDBACK_PIN → GND) |
| Multímetro | Modo corrente (A), de preferência com **peak-hold**; ponteiras jacaré |
| Fonte / bateria 5 V | Mesma alimentação do voo (o BEC entrega 5 V / 3 A; ver seção 5) |
| Cabo USB + terminal serial | 115200 baud |
| Cronômetro (fallback) | Se não houver microswitch |

## 3. Montagem (rig de bancada)

1. **Prenda a porta com a carga real**: monte o compartimento exatamente como no
   voo — porta articulada no eixo, velame empacotado dentro, elástico/mola
   tensionado no estado fechado (se o mecanismo tiver). A carga **precisa ser a
   real**, senão o teste não mede o risco.
2. **Servo**: sinal (amarelo/laranja) → GPIO 10 (`SERVO_PIN`); vermelho → +5 V;
   marrom → GND.
3. **Microswitch (opcional, recomendado)**: fixe na estrutura do compartimento de
   forma que a porta, **totalmente aberta**, pressione o botão. Ligue
   `FEEDBACK_PIN` (GPIO 4, padrão do sketch) → microswitch → GND. O sketch usa
   `INPUT_PULLUP`; porta aberta = nível `LOW`. Se não usar microswitch, deixe
   `FEEDBACK_PIN = -1` no sketch (modo manual, seção 4.4).
4. **Multímetro em série** (para corrente): corte/estenda o fio vermelho do servo
   e ligue o multímetro em série entre a fonte 5 V e o servo. Configure o modo
   **A (corrente)**, porta 10 A se disponível, e ative **peak-hold** para capturar
   o pico.
5. **Compile e grave**:
   ```bash
   arduino-cli compile --fqbn esp32:esp32:esp32s3 test/parachute_servo
   arduino-cli upload -p /dev/ttyUSB0 --fqbn esp32:esp32:esp32s3 test/parachute_servo
   ```
   Abra o monitor serial a **115200 baud**.

> 🔒 **Atenção:** não altere nada em `hardware/electronics/**` — contém mudanças
> pré-existentes de outro trabalho. Este teste vive em `test/` e `extras/`.

## 4. Procedimento

### 4.1 Regras gerais

- **Fixe os critérios ANTES do teste** (seção 6). Não afrouxe critérios depois de
  ver os resultados — se falhar, corrija o mecanismo.
- Entre cada tentativa: **re-empacote o velame e feche a porta** (a carga precisa
  ser re-armada do zero, igual ao pré-voo).
- Registre o log serial completo (copie/cole no analisador, seção 7).

### 4.2 Sequência de teste (20 tentativas)

1. Power-on: o sketch arma o servo em `CLOSED` (90°) — porta fechada/travada.
2. Feche a porta manualmente e re-empacote o velame (estado de pré-voo).
3. Envie **`o`** no serial → o sketch varre o servo de `CLOSED` a `OPEN` (90° → 0°)
   e mede o tempo até o microswitch acusar abertura total (ou pede o tempo do
   cronômetro, no modo manual).
4. O sketch segura `OPEN` por `HOLD_MS` (2 s) verificando que a porta **continua
   aberta** (elástico/mola não pode empurrar o servo de volta).
5. Registra a linha CSV (`RUN,OPEN_MS,TRIPPED,OPEN_FAIL,HOLD_FAIL`), volta para
   `CLOSED` e imprime `PASS`/`FAIL`.
6. Repita os passos 2–5 até **20 tentativas** (`REPETITIONS`). Envie **`s`** para
   ver a estatística parcial/quando quiser.
7. Ao final, envie **`s`** e registre o resumo. **Passe o veredito** (seção 6).

### 4.3 Medição de corrente (stall)

- Com o multímetro em série + peak-hold, anote o **pico de corrente de abertura**
  em cada tentativa (ou ao menos nas 20).
- Para a **corrente de stall real (rotor travado)**: com o mecanismo DESARMADO
  (sem porta), envie **`b`** — o sketch dá 2 s de aviso, vai a `OPEN` e segura por
  `STALL_HOLD_MS` (2 s) enquanto você **segura o braço do servo com a mão**,
  impedindo o movimento. Leia o pico no multímetro. Solte ao terminar.
  > ⚠️ Faça o teste bloqueado **por último e brevemente**: rotor travado = corrente
  > máxima + aquecimento. Não repita várias vezes seguidas.

### 4.4 Modo manual (sem microswitch)

Com `FEEDBACK_PIN = -1`, o sketch não detecta abertura: ele varre, imprime o
número da tentativa e pede `Enter measured open time (ms):`. Use um cronômetro
(ou vídeo em câmera lenta) do momento do comando até a porta abrir totalmente e
digite o valor. A verificação de *hold* fica desabilitada nesse modo — a porta
deve ser observada manualmente durante os 2 s seguintes.

## 5. Medição de corrente — como e por quê

O ESP32 não mede corrente (não há sensor no hardware). O procedimento é:

- Multímetro em série no fio **vermelho** (5 V) do servo, modo corrente, porta
  alta (10 A) ou peak-hold.
- Medir: (a) pico de corrente durante a abertura sob carga (cada tentativa) e
  (b) stall de rotor travado (comando `b`).
- **Por que importa:** a fonte de voo é um BEC 5 V / 3 A compartilhado com buzzer
  (~30 mA) e LoRa (~120 mA). Se a corrente de stall exceder a folga do rail, a
  tensão 5 V cai, o torque cai ainda mais e o ESP32 pode resetar — um falha dupla.
- **Corrente esperada:** para servo padrão 5 V com engrenagem metálica na faixa
  de ~4,8 kg·cm, o stall fica tipicamente entre **1,0 e 2,0 A**. Confirme contra
  o datasheet do servo real (ver seção 8).

## 6. Critérios de aprovação

Fixe antes de começar. Padrões sugeridos (ajuste às medidas do servo real **antes**
do primeiro run — nunca depois):

| # | Critério | Limite | Verificação |
|---|---|---|---|
| A | Abertura completa (porta no fim de curso) | **20/20 tentativas** | microswitch tripado (ou cronômetro, modo manual) |
| B | Tempo comando → abertura total | **< 1000 ms** em cada tentativa | `OPEN_MS` do log (servo especifica ~0,23 s/60° → ~345 ms sem carga; limite com folga para carga) |
| C | Porta permanece aberta (sem back-drive) | **20/20 tentativas** por ≥ 2000 ms | hold check do sketch |
| D | Corrente de pico de abertura | **≤ 1500 mA** (típico) | multímetro peak-hold |
| E | Corrente de stall (rotor travado) | **≤ 2500 mA** (teto do BEC: 3 A − buzzer − LoRa ≈ 2,7 A, com margem) | comando `b` + multímetro |

**Resultado final:** PASS se A–E passarem. Qualquer falha = FAIL do mecanismo
(só o servo em si não é aprovado).

## 7. Análise dos tempos

Copie o log serial (linhas `RUN,OPEN_MS,...`) para um arquivo e rode:

```bash
python3 extras/FSM_tester/analyze_servo_open_times.py log_servo.csv
# ou cole via stdin:
python3 extras/FSM_tester/analyze_servo_open_times.py < log_servo.csv
```

O script calcula média, desvio, pior caso e o veredito contra os critérios B/C
(exit code 0 = PASS, 1 = FAIL).

## 8. O que fazer se falhar

| Sintoma | Provável causa | Ação |
|---|---|---|
| Abertura lenta (> 1000 ms) ou não abre | Torque insuficiente | Servo maior/mais torque; alimentar o servo com 6 V direto (se o BEC permitir); verificar sag de tensão no 5 V durante o stall (fonte fraca derruba o torque) |
| Trava em posição intermediária | Atrito / interferência da porta | Lubrificar dobradiça/trilho; verificar se o velame empacotado prende na borda; aliviar pontos de contato |
| Porta não segura aberta (back-drive) | Elástico/mola forte demais para o servo em `OPEN` | Reduzir pré-carga da mola; mudar ponto de fixação do braço (mais alavanca); ou servo com maior torque de holding |
| Corrente de stall acima do teto | Servo subdimensionado / BEC marginal | Servo com menor corrente de stall; fonte dedicada para o servo; revisar o rail 5 V |
| Pico de corrente na abertura > 1,5 A | Mecanismo com muita resistência | Reduzir atrito antes de trocar o servo (item 2 acima) |

Regra geral: **primeiro reduza atrito/pré-carga, depois aumente torque** — a
margem de torque medida na bancada é a margem que existe em voo.

## 9. Registro de resultados (preencher na execução)

| Data | Operador | Servo (modelo) | Trials | Aberturas OK | Tempo médio (ms) | Pior caso (ms) | I pico abertura (mA) | I stall (mA) | Veredito |
|---|---|---|---|---|---|---|---|---|---|
| | | | 20 | | | | | | |

## 10. Notas técnicas

- **Servo real a confirmar:** `docs/hardware.md` especifica "metal gears, ~4,8
  kg·cm, ~9 g" — 9 g é faixa de micro servo (~1,8 kg·cm, ~0,7 A de stall), 4,8
  kg·cm é faixa de servo de ~55 g (~2 A de stall). **Identifique o modelo real e
  ajuste os critérios D/E ao datasheet** antes do primeiro run.
- **Constantes espelhadas:** `SERVO_PIN`, `SERVO_OPEN`, `SERVO_CLOSED` duplicam
  `firmware/config.h` de propósito (o sketch é standalone). Se mudar no firmware,
  mude aqui também.
- **Critério B × firmware:** o firmware manda `write(SERVO_OPEN)` uma única vez e
  segue a vida (não re-escrita periódica). O hold check mede se o servo segura a
  posição sozinho sem refresh — se falhar, o firmware pode precisar re-escrever a
  posição periodicamente após o deploy (discutir com o time de firmware).

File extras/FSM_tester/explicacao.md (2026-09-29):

# Explicação: Simulador de Máquina de Estados Finitos (FSM) para Foguete

## Visão Geral

Este código Python (`FSM_Tester.py`) simula uma **Máquina de Estados Finitos (FSM - Finite State Machine)** que será implementada em um **ESP32** para controle de voo de um foguete. O objetivo é testar a lógica de detecção de eventos de voo usando dados simulados ou reais antes de implementar o código no microcontrolador embarcado.

## Propósito do Código

O simulador serve para:

1. **Validar algoritmos de detecção** de fases de voo antes da implementação em hardware
2. **Ajustar parâmetros** (thresholds) de detecção com segurança
3. **Visualizar eventos** detectados em dados de voo reais ou simulados
4. **Garantir segurança** ao testar lógica crítica sem riscos ao hardware

## Arquitetura da FSM

A máquina de estados implementa **transições sequenciais** entre as fases de voo de um foguete:

```
IDLE (Repouso)
    ↓ [Aceleração > 15 m/s²]
LIFTOFF (Decolagem)
    ↓ [Aceleração < 2 m/s² OU az < -8 m/s²]
BURNOUT (Fim do Motor)
    ↓ [Velocidade vertical ≈ 0 E aceleração negativa]
APOGEE (Apogeu)
    ↓ [Aceleração total < 11.5 m/s² E descendo]
FREEFALL (Queda Livre)
    ↓ [Altitude ≤ 100m E descendo]
PARACHUTE (Paraquedas Aberto)
    ↓
LANDED (Pouso)
```

## Componentes Principais

### 1. Funções de Detecção de Estados

#### `detect_liftoff()` - Detecção de Decolagem
**Linha:** 117-139

**Critério:** Aceleração total > 15.0 m/s²

**Funcionamento:**
- Calcula aceleração total: `√(ax² + ay² + az²)`
- Ignição do motor causa pico súbito de aceleração
- Validações: verifica NaN/Inf para evitar falsos positivos

**Threshold ESP32:** `> 15.0 m/s²`

---

#### `detect_motor_burnout()` - Detecção de Fim do Motor
**Linha:** 18-55

**Critérios:**
1. Aceleração vertical < -8.0 m/s² (gravidade domina)
2. OU aceleração total < 2.0 m/s² (coasting)

**Funcionamento:**
- Detecta quando o motor para de gerar empuxo
- Requer altitude > 5m e velocidade vertical > 0.5 m/s (evita falsos positivos no solo)
- Fim da fase propulsada → início do voo balístico

**Thresholds ESP32:**
- `az < -8.0 m/s²` OU `total_acc < 2.0 m/s²`
- Altitude mínima: `5.0 m`
- Velocidade vertical mínima: `0.5 m/s`

---

#### `detect_apogee_acceleration()` - Detecção de Apogeu
**Linha:** 58-78

**Critérios:**
1. Velocidade vertical absoluta < 1.0 m/s (quase zero)
2. E aceleração vertical < -0.1 m/s² (descendo)

**Funcionamento:**
- Ponto mais alto da trajetória
- Velocidade vertical inverte de positiva para negativa
- Momento crítico para acionamento de sistema de recuperação

**Thresholds ESP32:**
- `|vz| < 1.0 m/s`
- `az < -0.1 m/s²`

---

#### `detect_freefall()` - Detecção de Queda Livre
**Linha:** 81-114

**Critérios:**
1. Aceleração total < 11.5 m/s² (próxima à gravidade)
2. E velocidade vertical < -5 m/s (descendo rapidamente)
3. E altura > 5m

**Funcionamento:**
- Detecta fase balística após apogeu
- Aceleração dominada pela gravidade (~9.8 m/s²)
- Estado anterior ao acionamento do paraquedas

**Thresholds ESP32:**
- `total_acc < 11.5 m/s²`
- `vz < -5 m/s`
- Altitude mínima: `5.0 m`

---

#### `altitude_trigger_factory()` - Gatilho de Altitude
**Linha:** 142-155

**Critério:** Altitude ≤ altitude_alvo (padrão: 100m)

**Funcionamento:**
- Factory function que cria gatilhos configuráveis por altitude
- Opção `require_descent=True` garante que só aciona durante descida
- Usado para abrir paraquedas em altitude segura

**Configuração ESP32:**
```python
PARACHUTE_ALTITUDE = 100  # metros
parachute_trigger = altitude_trigger_factory(PARACHUTE_ALTITUDE)
```

---

### 2. Processamento de Dados

#### Entrada de Dados (CSV)
**Linhas:** 5-16

**Formatos suportados:**
```csv
# dados_simulados.csv
millis, altp, ax, ay, az

# 13_30_11-Dados.csv e dados_filtrados.csv
millis, lat, lon, sat, alt, data, hora, altp, p, ax, ay, az, gx, gy, gz, pqd
```

**Campos utilizados:**
- `millis`: Timestamp em milissegundos (convertido para segundos)
- `altp`: Altitude barométrica em metros
- `ax, ay, az`: Acelerações nos eixos X, Y, Z em m/s²

---

#### Cálculo de Velocidade Vertical
**Linhas:** 189-202

**Método:** Diferenciação numérica
```python
vz = (altura_atual - altura_anterior) / (tempo_atual - tempo_anterior)
```

**Limites:**
- Clipping: `-200 m/s` a `+200 m/s`
- Evita valores espúrios em dados ruidosos

---

#### Vetor de Estado
**Linha:** 204
```python
state_vector = [x, y, height, vx, vy, vz]
```

**Componentes:**
- Posição: `[x, y, height]` - coordenadas espaciais (x e y não utilizados nesta versão)
- Velocidade: `[vx, vy, vz]` - componentes da velocidade (apenas vz utilizado)

---

#### Vetor de Aceleração
**Linha:** 205
```python
u_dot = [ax_dot, ay_dot, az_dot, ax, ay, az]
```

**Componentes:**
- Derivadas: `[ax_dot, ay_dot, az_dot]` - não utilizadas nesta versão
- Acelerações: `[ax, ay, az]` - leituras diretas dos acelerômetros

---

### 3. Loop Principal de Processamento
**Linhas:** 177-236

**Algoritmo:**
```
Para cada linha do CSV:
    1. Ler altitude e acelerações
    2. Calcular velocidade vertical (vz)
    3. Construir vetores de estado
    4. Verificar transições sequenciais:
       - SE não decolou E detect_liftoff() → LIFTOFF
       - SE decolou E não burnout E detect_motor_burnout() → BURNOUT
       - SE burnout E não apogeu E detect_apogee() → APOGEE
       - SE apogeu E não freefall E detect_freefall() → FREEFALL
       - SE freefall E não paraquedas E parachute_trigger() → PARACHUTE
    5. Registrar eventos detectados
```

**Características:**
- **Transições unidirecionais:** Estados só avançam, nunca retrocedem
- **Dependências em cadeia:** Cada estado requer que o anterior tenha ocorrido
- **Logging detalhado:** Imprime tempo, altitude, velocidades e acelerações de cada evento

---

### 4. Visualização
**Linhas:** 238-253

**Gráfico gerado:**
- **Eixo X:** Tempo em segundos
- **Eixo Y:** Altitude barométrica em metros
- **Marcadores:** Linhas verticais tracejadas em cada evento detectado
- **Labels:** Nome do evento (liftoff, burnout, apogee, freefall)

---

## Dados Simulados Utilizados

O código pode processar três tipos de arquivos CSV:

### 1. `dados_simulados.csv`
- Dados de simulação computacional
- 1.510 pontos de dados
- Trajetória idealizada sem ruído
- Melhor para validação inicial de lógica

### 2. `dados_filtrados.csv`
- Dados reais de voo filtrados
- 61 pontos (dados decimados)
- Inclui GPS, pressão barométrica, IMU completa
- Campo `pqd` indica acionamento de paraquedas

### 3. `13_30_11-Dados.csv`
- Dados de voo real completos
- 1.873 pontos de telemetria
- Sensor: IMU + GPS + barômetro
- Usado no código atual (linha 6)

---

## Tradução para ESP32

O código Python foi projetado para **tradução direta** para C++ no ESP32:

### Equivalências de Implementação

| Python | ESP32 (C++/Arduino) |
|---|---|
| `detect_liftoff()` | `bool detectLiftoff(float ax, float ay, float az)` |
| `detect_motor_burnout()` | `bool detectMotorBurnout(float height, float vz, float* accel)` |
| `detect_apogee()` | `bool detectApogee(float vz, float az)` |
| `detect_freefall()` | `bool detectFreefall(float height, float vz, float totalAccel)` |
| `numpy.sqrt()` | `sqrtf()` da biblioteca `<math.h>` |
| `pandas DataFrame` | Arrays circulares ou buffers de dados |
| Loop `for i, row in df.iterrows()` | `loop()` principal do Arduino |

### Exemplo de Implementação ESP32

```cpp
// Definição de estados
enum FlightState {
    IDLE,
    LIFTOFF,
    BURNOUT,
    APOGEE,
    FREEFALL,
    PARACHUTE_DEPLOYED,
    LANDED
};

FlightState currentState = IDLE;

// Variáveis de sensor
float ax, ay, az;        // Acelerômetro
float altitude;          // Barômetro
float vz = 0.0;         // Velocidade vertical calculada
float prevAltitude = 0.0;
unsigned long prevTime = 0;

void loop() {
    // 1. Ler sensores
    readIMU(&ax, &ay, &az);
    altitude = readBarometer();
    
    // 2. Calcular velocidade vertical
    unsigned long currentTime = millis();
    float dt = (currentTime - prevTime) / 1000.0;  // segundos
    if (dt > 0) {
        vz = (altitude - prevAltitude) / dt;
    }
    
    // 3. Máquina de estados
    switch(currentState) {
        case IDLE:
            if (detectLiftoff(ax, ay, az)) {
                currentState = LIFTOFF;
                Serial.println("LIFTOFF");
            }
            break;
            
        case LIFTOFF:
            if (detectMotorBurnout(altitude, vz, ax, ay, az)) {
                currentState = BURNOUT;
                Serial.println("BURNOUT");
            }
            break;
            
        case BURNOUT:
            if (detectApogee(vz, az)) {
                currentState = APOGEE;
                Serial.println("APOGEE");
            }
            break;
            
        case APOGEE:
            if (detectFreefall(altitude, vz, ax, ay, az)) {
                currentState = FREEFALL;
                Serial.println("FREEFALL");
            }
            break;
            
        case FREEFALL:
            if (altitude <= 100 && vz < 0) {
                currentState = PARACHUTE_DEPLOYED;
                deployParachute();  // Ativar servo/pirotécnico
                Serial.println("PARACHUTE");
            }
            break;
    }
    
    // 4. Atualizar histórico
    prevAltitude = altitude;
    prevTime = currentTime;
    
    delay(10);  // 100 Hz de atualização
}

bool detectLiftoff(float ax, float ay, float az) {
    float totalAccel = sqrtf(ax*ax + ay*ay + az*az);
    return totalAccel > 15.0;
}

bool detectMotorBurnout(float height, float vz, float ax, float ay, float az) {
    if (height < 5.0 || vz <= 0.5) return false;
    
    float totalAccel = sqrtf(ax*ax + ay*ay + az*az);
    return (az < -8.0) || (totalAccel < 2.0);
}

bool detectApogee(float vz, float az) {
    return (fabs(vz) < 1.0) && (az < -0.1);
}

bool detectFreefall(float height, float vz, float ax, float ay, float az) {
    if (height < 5.0 || vz >= -0.2) return false;
    
    float totalAccel = sqrtf(ax*ax + ay*ay + az*az);
    return (totalAccel < 11.5) && (vz < -5);
}
```

---

## Funcionalidades de Segurança

### 1. Validação de Dados
**Implementado em todas as funções de detecção:**
```python
if not all(np.isfinite([ax, ay, az])):
    return False
```

**Previne:**
- Leituras NaN (Not a Number)
- Valores infinitos
- Overflow/underflow numérico

---

### 2. Guardas de Estado
**Exemplo em `detect_motor_burnout()` (linhas 47-48):**
```python
if height < 5.0 or vz <= 0.5:
    return False
```

**Propósito:**
- Evita falsos positivos no solo (altura < 5m)
- Garante que o foguete está em movimento ascendente
- Previne acionamentos prematuros

---

### 3. Transições Condicionais
**Linha 213:**
```python
elif not burnout and detect_motor_burnout(...) and liftoff:
```

**Lógica:**
- `not burnout`: Evento ainda não ocorreu
- `detect_motor_burnout()`: Condição física atendida
- `and liftoff`: Estado anterior confirmado

**Resultado:** Transições só ocorrem na sequência correta

---

### 4. Suavização Opcional
**Linhas 180-187 (comentadas):**
```python
# height = smooth(height, prev_height, alpha=0.2)
```

**Função `smooth()` (linhas 171-174):**
```python
def smooth(value, prev_value, alpha):
    return alpha * value + (1 - alpha) * prev_value
```

**Aplicação:**
- Filtro passa-baixa (exponential moving average)
- Alpha = 0.2: 20% valor novo, 80% histórico
- Reduz ruído dos sensores
- **Comentado** para preservar resposta rápida

---

## Ajustes de Parâmetros (Tuning)

### Thresholds Críticos

| Parâmetro | Valor | Localização | Efeito ao Aumentar |
|---|---|---|---|
| Aceleração de Liftoff | 15.0 m/s² | Linha 137 | Detecção mais tardia, menos falsos positivos |
| Aceleração de Burnout | 2.0 m/s² | Linha 53 | Detecção mais tardia |
| Az negativo (Burnout) | -8.0 m/s² | Linha 53 | Detecção mais sensível a gravidade |
| Velocidade de Apogeu | 1.0 m/s | Linha 76 | Janela de detecção mais estreita |
| Aceleração de Freefall | 11.5 m/s² | Linha 112 | Detecção mais próxima de ~1g |
| Velocidade de Freefall | -5 m/s | Linha 112 | Requer descida mais rápida |
| Altitude de Paraquedas | 100 m | Linha 158 | Abertura mais alta/baixa |

### Recomendações para Ajuste

1. **Liftoff:** Aumentar threshold se houver vibrações pré-voo
2. **Burnout:** Ajustar baseado no perfil do motor (thrust curve)
3. **Apogeu:** Reduzir `|vz|` para foguetes com apogeu baixo
4. **Freefall:** Ajustar para arrasto aerodinâmico do foguete
5. **Paraquedas:** Considerar velocidade terminal e altura mínima segura

---

## Limitações e Melhorias Futuras

### Limitações Atuais

1. **Sem Filtro de Kalman:** Velocidade calculada por diferenciação simples (ruidosa)
2. **Eixos X/Y ignorados:** Não detecta instabilidade lateral
3. **Sem validação de GPS:** Altitude barométrica pode ter drift
4. **Hardcoded thresholds:** Valores fixos não adaptam a diferentes foguetes
5. **Sem detecção de pouso:** FSM para em freefall/paraquedas

### Melhorias Sugeridas para ESP32

1. **Filtro de Kalman:** Fusão de sensores (barômetro + acelerômetro + GPS)
2. **Watchdog timer:** Reset automático se FSM travar
3. **Log em SD Card:** Gravar telemetria completa para análise pós-voo
4. **Redundância:** Múltiplos critérios para eventos críticos (ex: apogeu)
5. **Calibração automática:** Ajuste de thresholds baseado em pré-voo
6. **Detecção de anomalias:** Tumbling, perda de sinal, falha de sensor
7. **Estado de pouso:** Detectar impacto e estabilização

---

## Fluxo de Desenvolvimento

```
┌──────────────────────────────────────────────────┐
│  1. SIMULAÇÃO (Python - FSM_Tester.py)           │
│     - Testar lógica com dados históricos         │
│     - Ajustar thresholds                          │
│     - Visualizar eventos                          │
└────────────────────┬─────────────────────────────┘
                     ↓
┌──────────────────────────────────────────────────┐
│  2. TRADUÇÃO (C++/Arduino)                       │
│     - Implementar funções de detecção            │
│     - Adaptar para leitura de sensores real-time │
│     - Adicionar máquina de estados switch-case   │
└────────────────────┬─────────────────────────────┘
                     ↓
┌──────────────────────────────────────────────────┐
│  3. TESTES EM BANCADA (ESP32 + Sensores)        │
│     - Simular acelerações manualmente            │
│     - Validar leituras de sensores               │
│     - Testar acionamento de servo/pirotécnico    │
└────────────────────┬─────────────────────────────┘
                     ↓
┌──────────────────────────────────────────────────┐
│  4. VOO TESTE (Foguete real)                     │
│     - Coletar telemetria real                    │
│     - Analisar eventos detectados                │
│     - Refinar thresholds se necessário           │
└────────────────────┬─────────────────────────────┘
                     ↓
┌──────────────────────────────────────────────────┐
│  5. ITERAÇÃO (Retornar ao passo 1)               │
│     - Analisar dados do voo teste                │
│     - Ajustar simulação com dados reais          │
│     - Melhorar algoritmos                         │
└──────────────────────────────────────────────────┘
```

---

## Conclusão

Este simulador é uma ferramenta essencial para desenvolvimento seguro de software de voo. Ele permite:

✅ **Validar** lógica de detecção sem risco ao hardware  
✅ **Iterar rapidamente** em ajustes de parâmetros  
✅ **Visualizar** comportamento da FSM em dados reais  
✅ **Traduzir facilmente** para implementação em ESP32  

A arquitetura modular e os critérios defensivos garantem que o código seja **robusto**, **testável** e **pronto para produção** em sistemas críticos de segurança como computadores de voo de foguetes.

---

## Referências

- Código fonte: `FSM_Tester.py`
- Dados de voo: `13_30_11-Dados.csv`, `dados_simulados.csv`, `dados_filtrados.csv`
- Notebook de análise: `OpenCSV.ipynb`
- Documentação ESP32: [Espressif Official Docs](https://docs.espressif.com/)

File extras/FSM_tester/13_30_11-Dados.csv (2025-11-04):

millis | lat | lon | sat | alt | data | hora | altp | p | ax | ay | az | gx | gy | gz | pqd
7060 | -22.590936 | -42.764552 | 10 | 11.70 | N/A | 13:30:11 | -0.10 | 1026.58 | 1.99 | 9.19 | 0.83 | -0.08 | 0.01 | 0.00 | 0
7260 | -22.590936 | -42.764552 | 10 | 11.70 | N/A | 13:30:11 | 0.03 | 1026.57 | 1.91 | 9.36 | 0.71 | -0.06 | 0.02 | 0.03 | 0
7460 | -22.590936 | -42.764552 | 10 | 11.70 | N/A | 13:30:11 | -0.11 | 1026.59 | 1.99 | 9.40 | 0.89 | -0.08 | 0.06 | 0.02 | 0
7660 | -22.590936 | -42.764552 | 10 | 11.70 | N/A | 13:30:11 | -0.11 | 1026.59 | 1.79 | 9.26 | 0.91 | -0.09 | 0.03 | 0.02 | 0
7911 | -22.590937 | -42.764552 | 10 | 11.70 | 2025/6/2 | 13:30:13 | -0.30 | 1026.61 | 1.94 | 9.57 | 1.23 | -0.12 | 0.03 | 0.07 | 0
8137 | -22.590937 | -42.764552 | 10 | 11.80 | 2025/6/2 | 13:30:13 | -0.20 | 1026.60 | 1.87 | 9.23 | 1.58 | 0.04 | 0.09 | 0.09 | 0
8363 | -22.590937 | -42.764552 | 10 | 11.80 | 2025/6/2 | 13:30:13 | -0.16 | 1026.59 | 1.18 | 9.27 | -0.17 | 0.33 | 0.46 | 0.14 | 0
8594 | -22.590937 | -42.764552 | 10 | 11.80 | 2025/6/2 | 13:30:13 | -0.04 | 1026.58 | 1.55 | 9.39 | -0.59 | 0.22 | -0.14 | -0.01 | 0
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

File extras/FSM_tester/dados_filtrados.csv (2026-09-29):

millis | lat | lon | sat | alt | data | hora | altp | p | ax | ay | az | gx | gy | gz | pqd
0.0 | -22.590942 | -42.764539 | 12 | 12.5 | 2025/6/2 | 13:37:46 | 2.36 | 1026.28 | -1.09 | 19.61 | 2.81 | 0.23 | -1.27 | -0.32 | 0
0.241 | -22.59094 | -42.764538 | 12 | 17.7 | 2025/6/2 | 13:37:47 | 8.23 | 1025.57 | 2.18 | 19.61 | 2.99 | 0.87 | 2.32 | -0.37 | 0
0.497 | -22.59094 | -42.764538 | 12 | 17.7 | 2025/6/2 | 13:37:47 | 16.98 | 1024.51 | -5.26 | 19.61 | 1.46 | -1.08 | 1.9 | -0.07 | 0
0.746 | -22.59094 | -42.764538 | 12 | 17.7 | 2025/6/2 | 13:37:47 | 24.59 | 1023.58 | -4.7 | 19.61 | 7.66 | 0.35 | 2.75 | 0.54 | 0
0.997 | -22.59094 | -42.764538 | 12 | 17.7 | 2025/6/2 | 13:37:47 | 40.35 | 1021.67 | 6.75 | 19.61 | 8.54 | -0.02 | 0.5 | 0.35 | 0
1.285 | -22.59094 | -42.764538 | 12 | 17.7 | 2025/6/2 | 13:37:47 | 63.9 | 1018.82 | 1.89 | 9.88 | -1.78 | 0.23 | -0.37 | 0.23 | 0
1.52 | -22.590869 | -42.764568 | 12 | 16.5 | 2025/6/2 | 13:37:48 | 78.05 | 1017.11 | -0.34 | -0.87 | -1.61 | 0.06 | -0.9 | 0.09 | 0
1.758 | -22.590869 | -42.764568 | 12 | 16.5 | 2025/6/2 | 13:37:48 | 95.84 | 1014.96 | 0.51 | -5.23 | -0.64 | -0.05 | -0.99 | 0.07 | 0
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

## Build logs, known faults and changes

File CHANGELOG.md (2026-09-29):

# Changelog

All notable changes to this project will be documented in this file.

The format is based on [Keep a Changelog](https://keepachangelog.com/en/1.0.0/),
and this project adheres to [Semantic Versioning](https://semver.org/).

## [Unreleased] — LASC 2026 Post-Flight

### Flight-Critical Fix
- **50 Hz → 5 Hz flight loop** (`d0865ee`): Thonyan flight #51 (2026-09-03)
  descended ballistically — parachute never deployed. Root cause: the 50 Hz
  loop outran the BMP585's ~25 Hz effective conversion rate, causing `vz` to
  alternate between 0.00 (stale cycle) and 2×real (double step over the 20 ms dt).
  Both `PARACHUTE_CONFIRM_CYCLES=3` and `FREEFALL_BACKSTOP_CYCLES=50` —
  consecutive-cycle gates — never survived the interleaved zeros.
  At 5 Hz, every cycle sees a fresh baro conversion → `vz` continuous →
  deploy confirmed at 317 m (+0.6 s after apogee, apogee 359 m; MC: 968 m).
  Validated: `extras/FSM_tester/validate_fsm_5hz.py` reproduces the failure
  numerically (50 Hz stale model → deploy=None; 5 Hz → deploy at 317 m).
- All cycle-count constants rescaled to preserve absolute times:
  backstop 50→5, baro-stale 125→13, arming rezero 150→15, glitch 50→5,
  liftoff-alt-confirm 3→1. `LIFTOFF_CONFIRM_MS` (100 ms) and
  `PARACHUTE_CONFIRM_CYCLES` (3 = 600 ms) unchanged.

### Fixed
- **Servo pin + team ID alignment** (`4dc4aca`): `SERVO_PIN` 7→39 (pin 7
  was floating on ESP32-S3 DevKitC — chute would not actuate even with the
  FSM calling deploy). `TEAM_ID` #51→#11 (Serra Rocketry canonical).
- **Hardware schematic**: R1 (servo signal) 1k→220Ω (bench measurement —
  1k was clamping GPIO39 output swing, causing servo jitter).
- **Sensor init retry** (`c86a324`): BMP585/LSM6DS3 sometimes fail `begin()`
  on first power-up; retry within 10 s window with buzzer feedback per attempt.
- Buffer overflow fix in GPSModule (`sprintf` → `snprintf`).
- Sensor fallback on corrupted readings (NaN/range validation, last-good
  value preservation).

### Added
- **Emergency deploy board** (`25cee6b`): standalone ESP32-C3 SuperMini
  firmware with barometer-only FSM (BMP280 + servo GPIO19, 10 Hz loop).
  Deploys chute if main S3 computer fails to init or FSM gets stuck.
  Includes `bench_emergency.ino` self-test.
- **Thonyan #51 post-flight data** (`211b0b2`, `110657f`): raw RX log (38
  packets), parsed CSV, Jupyter analysis notebook, vz comparison chart.
- Random TX jitter on telemetry period (satellite #213 collision avoidance).

### Changed
- FlightControlTask rate: 50 Hz → 5 Hz (all cycle constants rescaled).
- `LIFTOFF_CONFIRM_MAX_GAP_MS`: 60→200 ms (one 5 Hz frame tolerance).
- `LIFTOFF_ALT_CONFIRM_CYCLES`: 3→1 (one 5 Hz frame = 200 ms).
- Private member naming aligned with v2.0 convention (snake_case → _camelCase).

### Documentation
- Consolidated `firmware/REFACTORING_PLAN.md` → `docs/architecture.md`
  (1,313 lines → living reference with safety validation summary).
- Consolidated `firmware/MODULOS.md` → `docs/modules.md`.
- Removed legacy `firmware/MODULOS.md` and `firmware/REFACTORING_PLAN.md`
  (content preserved in docs/).
- Updated `README.md`, `docs/software.md`, `docs/flowchart.md`, `AGENTS.md`
  for 5 Hz and new doc structure.

### Flight Records
- **`flight_records/` directory**: centralized post-flight data per mission.
- **Thonyan #51** (Dedalo): ballistic descent, no deploy. Apogee 359 m
  (MC: 968 m). Deploy altitude if fix had been active: 317 m.
- **Dedalo** (mission data): `extras/FSM_tester/flight_results_dedalo.csv`.
- Golden RocketPy simulation: apogee 951 m → deploy 949 m (PASS).

---

## [2.0.0] - 2026-07-19

### Added
- **Phase 1-2: Project structure and base interfaces**
  - `firmware/sensors/ISensor.h` — Abstract interface for all sensors (BMP585, LSM6DS3, GPS)
  - `firmware/flight/SensorData.h` — Shared data structures (SensorData, LogMessage)
  - Sensor abstraction layer enabling polymorphic sensor implementations
  - FreeRTOS-compatible data structures for inter-task communication via queues
  - Complete Doxygen documentation for all interfaces

- **Phase 3: BMP585Sensor class**
  - Barometric altitude, pressure, temperature reading
  - Vertical velocity (Vz) via numerical differentiation, clipped to ±200 m/s
  - NaN/Inf and range validation with fallback to last known good value
  - IIR low-pass filter (alpha=0.2) for accelerometer data

- **Phase 4: LSM6DS3Sensor class**
  - 6-axis accelerometer + gyroscope with safety validations
  - NaN/Inf rejection and range checking (±200 m/s² accel, ±2000 °/s gyro)
  - Vector accessors via pointer parameters (`getAcceleration`, `getGyroscope`)

- **Phase 5: GPSModule class**
  - Non-blocking NMEA parsing via TinyGPS++ at 5Hz
  - HardwareSerial dependency injection for testability
  - GPS time used for CSV file naming (NOFIX fallback)

- **Phase 6: 4-state Flight State Machine**
  - IDLE → ASCENT → DESCENT → LANDED with sub-event flags (liftoff, burnout, apogee, freefall, parachute)
  - Thresholds validated against real flight data (1,873 points from `13_30_11-Dados.csv`)
  - IIR filter with seed on first reading (avoids transient)
  - Parachute deploy with multi-cycle confirmation (3 cycles of stable negative Vz)
  - Ground guard (50m) preventing deployment near terrain

- **Phase 7: FreeRTOS multi-task architecture**
  - **FlightControlTask** (Core 1, Priority 20, 5 Hz): sensor reads + FSM + parachute + watchdog
  - **TelemetryTask** (Core 0, Priority 5, 5Hz): GPS + queue drain + LoRa + file logging
  - **LoggerTask** (Core 0, Priority 1): async log queue with level filtering
  - Queue-based inter-task communication (no shared variables)
  - ESP32 TWDT armed inside the running task (not in init)
  - Performance metrics (cycle count, overruns, queue drops, exec time)

- **Phase 8: firmware.ino integration**
  - `setup()` delegates to `initFlightControlTask()` / `initTelemetryTask()` / `initLoggerTask()`
  - Safe-hold on critical failure (infinite loop + buzzer) — no `ESP.restart()`
  - `loop()` blocks on `vTaskDelay(portMAX_DELAY)`; all work in FreeRTOS tasks

- **Phase 9: Module adaptation**
  - `parachute_module` — Servo actuator (one-shot, idempotent deploy)
  - `lora_module` — RFM95W at 915 MHz, SF7, BW125k, CR4/5, CRC enabled
  - `filesystem_module` — SD card primary + LittleFS fallback, transparent dispatch
  - `buzzer_module` — Status tones (init success/failure)

- **Phase 10: Telemetry format (22 fields)**
  - CSV format aligned with `recovery-webui` receiver: `TEAM_ID,millis,count,altp,temp,umi,p,gx,gy,gz,ax,ay,az,vz,maxAltitude,state,alt,lat,lon,sat,parachute,rssi`
  - Single `snprintf` call (no heap fragmentation)
  - GPS enrichment in TelemetryTask (not FlightControlTask)

### Changed
- Migrated from v1.0 procedural architecture to v2.0 Object-Oriented design
- Restructured firmware directory: `sensors/`, `flight/`, `modules/`
- **FSM simplified to 4 main states** with internal event flags (was 7-state model)
- Replaced BMP280 with BMP585 (I2C, improved accuracy)
- Replaced MPU6050 with LSM6DS3 (6-axis, better range)
- Replaced NEO-6M GPS with NEO-8M (multi-constellation)
- Removed WiFi AP + Web server (v1.0 feature, not needed in v2.0)
- Updated `docs/software.md` with new module structure and component mapping
- Pin table in `docs/hardware.md` updated for ESP32-S3 pinout
- `docs/flowchart.md` rewritten for FreeRTOS + 4-state FSM
- `CONTRIBUTING.md` rewritten for v2.0 workflows

### Fixed
- **Critical Safety Initializations**:
  - All SensorData struct fields now have safe default values
  - LogMessage buffer initialized with zero-terminator
  - Prevents undefined behavior from uninitialized variables
  - Ensures parachute_deployed flag cannot be random on startup
  - Protects against NaN propagation in FSM transitions

### Documentation Added
- `docs/adr/002-sensor-abstraction.md` — Architectural Decision Record for ISensor interface

---

## [1.0.0] - 2026-01-27

### Added
- Initial project structure
- Base firmware for ESP32-C3 Super Mini
- Altitude monitoring system (MPU6050 sensor)
- GPS integration
- LoRa communication with operational base
- Telemetry storage in LittleFS
- Web interface for data access
- Component unit tests
- Software and hardware documentation

### Release Notes
- First functional version of the onboard computer
- Parachute deployment system still under testing
- Sensor calibration required before flight

---

## Versioning Guide

### MAJOR (X.0.0)
- Incompatible changes to firmware API or data structure

### MINOR (0.X.0)
- New features backward compatible with previous version
- Functionality improvements

### PATCH (0.0.X)
- Bug fixes
- Performance optimizations
- Documentation updates

## How to Report Changes

When making commits or pull requests, use the following categories:

- `feat:` for new features
- `fix:` for bug fixes
- `docs:` for documentation
- `test:` for tests
- `refactor:` for code refactoring
- `perf:` for performance improvements
- `chore:` for maintenance tasks

Example: `feat: add temperature sensor`

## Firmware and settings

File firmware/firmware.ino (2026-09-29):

/**
 * @file firmware.ino
 * @brief Main firmware entry point for #11 Flight Computer (Avionics System)
 * 
 * This is the main program file for a rocket flight computer that handles
 * sensor data collection, parachute deployment, telemetry transmission, and
 * data storage. The system uses a modular architecture with separate header files
 * for each subsystem.
 * 
 * System capabilities:
 * - Altitude and atmospheric pressure monitoring (BMP585)
 * - Inertial measurement unit for orientation (LSM6DS3)
 * - GPS position and time tracking
 * - Long-range telemetry via LoRa radio
 * - Autonomous parachute deployment based on flight profile (apogee, Option A)
 * - Data logging to onboard flash storage (LittleFS)
 * - Audio feedback via buzzer for system status
 * 
 * Flight phases:
 * 1. Initialization: System startup and sensor calibration
 * 2. Pre-launch: Monitoring and data collection on ground
 * 3. Ascent: High-frequency data logging during powered flight
 * 4. Apogee detection: Tracking maximum altitude
 * 5. Descent: Parachute deployment at apogee and controlled landing
 * 6. Recovery: Post-flight data access via storage retrieval
 * 
 * @note All configuration parameters are in config.h
 * @note FlightControlTask runs at 50Hz (FLIGHT_CONTROL_PERIOD_MS);
 *       TelemetryTask and LoggerTask run at 5Hz.
 * 
 * @author Serra Rocketry
 * @date 2026
 */

//==============================================================================
// MODULE INCLUDES
//==============================================================================

#include "config.h"             // Global configuration and constants

#include "sensors/BMP585Sensor.h"
#include "sensors/LSM6DS3Sensor.h"
#include "sensors/GPSModule.h"
#include "flight/FlightStateMachine.h"
#include "flight/FlightControlTask.h"
#include "flight/TelemetryTask.h"
#include "flight/LoggerTask.h"


#include "modules/buzzer_module.h"
#include "modules/filesystem_module.h"
#include "modules/lora_module.h"
#include "modules/parachute_module.h"

//==============================================================================
// SETUP - ONE-TIME INITIALIZATION
//==============================================================================

/**
 * @brief Initialize all system components and prepare for flight
 * 
 * This function runs once at power-on and delegates subsystem startup to the
 * task init functions (each owns its objects, buses, queues and watchdog):
 *  - initFlightControlTask(): Wire (I2C) + BMP585 + LSM6DS3 + FSM +
 *    sensorDataQueue + servo
 *  - initTelemetryTask(): SPI remap + GPS + telemetry queue consumer +
 *    LoRa/file fan-out
 *  - initLoggerTask(): logQueue + Serial/file logger
 * 
 * @note Serial monitor must be set to 115200 baud
 * @note The watchdog (TWDT) is armed inside taskFlightControl once it is
 *       actually running, not here, to avoid a dangling armed watchdog.
 *
 * On any critical init failure the system prints the error, flushes Serial,
 * and enters an infinite loop with the buzzer blinking — it does NOT call
 * ESP.restart() to avoid losing state in flight.
 * 
 * @see setup() is called automatically once by Arduino framework
 */
void setup() {
  Serial.begin(115200);
  pinMode(BUZZER_PIN, OUTPUT);

  // I2C/SPI bus init is owned by the subsystems that use it:
  //   - Wire.begin()      -> initFlightControlTask() (BMP585 + LSM6DS3)
  //   - SPI.begin() remap -> initTelemetryTask(), BEFORE setupStorage()
  //     (SD.begin uses the global SPI object; without the pin remap the SD
  //     card is probed on the ESP32-S3 default SPI pins and always falls
  //     back to LittleFS. setupLoRa() re-issues SPI.begin() — idempotent.)

  bool initOk = true;
  String initFail = "";

  if (!initFlightControlTask()) {
    initFail = "FATAL: FlightControl init failed (sensors/servo?)";
    initOk = false;
  } else if (!initTelemetryTask()) {
    initFail = "FATAL: Telemetry init failed (LoRa/FS/GPS?)";
    initOk = false;
  } else if (!initLoggerTask()) {
    initFail = "FATAL: Logger init failed";
    initOk = false;
  }

  if (!initOk) {
    // Safe-hold: do NOT reboot in a loop (would lose state in flight and
    // hides the error). Print clearly, flush, and blink the buzzer as alarm.
    Serial.println(initFail);
    Serial.flush();
    Serial.println("Halting — check wiring/sensors. Buzzer alarm active.");
    Serial.flush();
    for (;;) {
      // Alarm tone at the piezo resonance — a passive piezo needs a square
      // wave (digitalWrite DC is silent). Same frequency as the normal Beep.
      tone(BUZZER_PIN, BUZZER_TONE_HZ, 400);
      vTaskDelay(pdMS_TO_TICKS(500));
    }
  }
}

void loop() {
  vTaskDelay(portMAX_DELAY);

}

//==============================================================================
// MAIN LOOP - CONTINUOUS OPERATION
//==============================================================================

/**
 * @brief Main flight computer control loop
 * 
 * Intentionally empty: all real-time work happens in the FreeRTOS tasks
 * created by the init functions (FlightControl @50Hz, Telemetry @5Hz,
 * Logger @5Hz). The loop blocks forever on portMAX_DELAY so the Arduino
 * framework's loop() does not spin.
 * 
 * Parachute deployment (safety-critical) is decided by FlightStateMachine
 * on apogee detection (Option A) and actuated by taskFlightControl — not
 * here.
 */

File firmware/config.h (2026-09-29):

/**
 * @file config.h
 * @brief Global configuration file for the avionics system
 * 
 * This file contains all pin definitions, constants, and parameters
 * used throughout the system. Centralizing configurations here makes
 * maintenance and parameter modifications easier.
 * 
 * @author #11
 * @date 2026
 */

#ifndef CONFIG_H
#define CONFIG_H

#include <Arduino.h>

//==============================================================================
// LORA COMMUNICATION CONFIGURATION
//==============================================================================

/**
 * LoRa module operating frequency in Hz
 * 915 MHz is the ISM frequency for Brazil/Americas (matches receiver-lora).
 * (868 MHz is Europe — do not use here.)
 */
#define LORA_FREQ 915E6

/**
 * SPI bus pins shared between LoRa (RFM95W) and SD card.
 * Wired on the ESP32-S3-DEVKITC-1-N8R8 schematic (2026-08):
 *   SCK  = GPIO12, MISO = GPIO13, MOSI = GPIO11, CS_LORA = GPIO10
 * @note The LoRa 0.8.0 library uses the global SPI object. We remap the SPI
 *       bus to these pins via SPI.begin(SCK, MISO, MOSI, SS) in setupLoRa()
 *       (same approach as the receiver-lora firmware, which compiles/runs
 *       clean). Only CS/RST/DIO0 are passed to LoRa.setPins().
 */
#define LORA_SCK  12
#define LORA_MISO 13
#define LORA_MOSI 11
#define SS_LORA 10

/**
 * Reset pin for LoRa module (RFM95W).
 * Schematic: GPIO4 on ESP32-S3-DEVKITC-1-N8R8.
 */
#define RST_LORA 4

/**
 * DIO0 pin of LoRa module (IRQ / interrupt).
 * Schematic: GPIO5 on ESP32-S3-DEVKITC-1-N8R8.
 */
#define DIO0_LORA 5

/**
 * Synchronization word for LoRa communication
 * Ensures only devices with the same word communicate
 * Change this value to create isolated LoRa networks
 */
#define SYNC_WORD 0xF3

// Spreading factor / bandwidth / coding rate / TX power.
// Explicitly matched to the receiver (recovery-webui/components/receiver-lora)
// so the link connects. These are also the LoRa.h defaults, but we set them
// explicitly to avoid relying on library defaults.
#define LORA_SF       7      // Spreading Factor 7–12
#define LORA_BW       125E3  // Bandwidth Hz
#define LORA_CR       5      // Coding Rate (4/5)
#define LORA_TX_POWER 17     // dBm

//==============================================================================
// PIN DEFINITIONS - SD CARD (SPI, shares bus with LoRa)
//==============================================================================

/**
 * Chip Select pin for SD card module.
 * Shares the SPI bus with LoRa (SCK=12, MISO=13, MOSI=11, CS_LORA=10).
 * Schematic: GPIO14 on ESP32-S3-DEVKITC-1-N8R8.
 * @note If SD fails, data is saved to LittleFS (internal flash) automatically.
 */
#define SD_CS_PIN 14

/**
 * Flush file buffer every N samples when using SD card
 * Balances data safety vs. write endurance.
 */
static constexpr uint8_t FLUSH_EVERY_N = 10;

//==============================================================================
// PIN DEFINITIONS - ACTUATORS
//==============================================================================

/**
 * Digital pin connected to parachute servo motor.
 * Uses PWM to control servo position.
 * Schematic: GPIO7 on ESP32-S3-DEVKITC-1-N8R8.
 * @note Two servo footprints (M1, M2) on the schematic share this same PWM
 *       signal — confirm with the assembler whether the build uses one or both.
 */
#define SERVO_PIN 39

/**
 * Digital pin connected to piezoelectric buzzer.
 * Emits sound signals for status indication.
 * Schematic: GPIO6 on ESP32-S3-DEVKITC-1-N8R8.
 * @note Avoid GPIO0 (boot strap).
 */
#define BUZZER_PIN 6

/**
 * Tone frequency for the passive piezo buzzer (Hz).
 * @note Bench resonance sweep (test/bench `z`, 2026-08-27): loudest point
 *       of the 2.0-4.0 kHz scan. The piezo is PASSIVE — drive with tone()/
 *       LEDC square wave; digitalWrite DC produces no sound.
 */
#define BUZZER_TONE_HZ 2700

//==============================================================================
// PIN DEFINITIONS - I2C (SENSORS: BMP585 barometer, LSM6DS3 IMU)
//==============================================================================

/**
 * I2C data pin (SDA) for the sensor bus.
 * @note ESP32-S3 Arduino core default is SDA=8 / SCL=9. The BMP585 and
 *       LSM6DS3 drivers call begin_I2C() with no pins, so they use this
 *       default. Wire.begin() in initFlightControlTask() also uses these.
 *       Keep the schematic wired to 8/9 (or change both here and the calls).
 */
#define I2C_SDA 8

/**
 * I2C clock pin (SCL) for the sensor bus.
 */
#define I2C_SCL 9

/**
 * I2C 7-bit address of the LSM6DS3 IMU.
 * Bench-measured via brute-force I2C scan (2026-08-27): responds at 0x6B
 * (the LSM6DS3 alternates 0x6A/0x6B depending on the SDO/SA0 strap).
 */
#define I2C_ADDR_LSM6DS3 0x6B
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

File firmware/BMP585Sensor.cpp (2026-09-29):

/**
 * @file BMP585Sensor.cpp
 * @brief Implementation of BMP585 barometric sensor driver
 * 
 * @see BMP585Sensor.h for class definition
 * @see firmware/REFACTORING_PLAN.md Fase 3
 */

#include "sensors/BMP585Sensor.h"
#include "config.h"

BMP585Sensor::BMP585Sensor()
    : _ready(false), _useBMP585(true), _basePressure(0.0F), _altitude(0.0F), _temperature(0.0F),
      _pressure(0.0F), _maxAltitude(0.0F), _prevAltitude(0.0F), _prevTime(0UL),
      _spikeStreak(0),
      _verticalVelocity(0.0F) {}

/**
 * @brief Initializes BMP585 sensor and calibrates base pressure
 * 
 * Performs I2C communication test, first reading validation, and
 * base pressure calibration (single sample at startup).
 * 
 * @return true if initialization successful, false on error
 * @note Blocking: performs one sensor reading during calibration
 */
bool BMP585Sensor::begin() {
  // Primary: BMP585 at the factory-default address (0x46; CSB strap = 0x47).
  // Post-begin config mirrors the working satellite implementation
  // (satellite/src/sensors/BME280Sensor.cpp) — without setPowerMode(NORMAL)
  // the chip stays in standby and performReading() can fail.
  bool found585 = false;
  for (uint8_t a : {I2C_ADDR_BMP585, I2C_ADDR_BMP585_ALT}) {
    if (!_bmp.begin(a, &Wire)) {
      continue;
    }
    _bmp.setTemperatureOversampling(BMP5XX_OVERSAMPLING_8X);
    _bmp.setPressureOversampling(BMP5XX_OVERSAMPLING_16X);
    _bmp.setIIRFilterCoeff(BMP5XX_IIR_FILTER_COEFF_3);
    _bmp.setOutputDataRate(BMP5XX_ODR_25_HZ);
    _bmp.setPowerMode(BMP5XX_POWERMODE_NORMAL);
    _useBMP585 = true;
    found585 = true;
    break;
  }
  if (!found585) {
    // Fallback: BMP280 (satellite BME280Sensor.cpp pattern) — try both
    // strap-selected addresses. Sampling mirrors the satellite config.
    Serial.println("BMP585 not found, trying BMP280 fallback...");
    bool found280 = false;
    for (uint8_t addr : {I2C_ADDR_BMP280_PRIMARY, I2C_ADDR_BMP280_ALT}) {
      if (_bmp280.begin(addr)) {
        _bmp280.setSampling(Adafruit_BMP280::MODE_NORMAL,
                            Adafruit_BMP280::SAMPLING_X2,
                            Adafruit_BMP280::SAMPLING_X16,
                            Adafruit_BMP280::FILTER_X16,
                            Adafruit_BMP280::STANDBY_MS_1);  // fastest for 5 Hz loop
        _useBMP585 = false;
        found280 = true;
        Serial.println("BMP280 fallback active (backend=bmp280).");
        break;
      }
    }
    if (!found280) {
      Serial.println("BMP585 initialization failed (no BMP280 fallback either).");
      _ready = false;
      return false;
    }
  }

  if (!_firstReading()) {
    Serial.println("Barometer first reading failed.");
    _ready = false;
    return false;
  }

  _ready = true;
  return true;
}

bool BMP585Sensor::reinit() {
  Serial.println("[BMP585] reinit: sensor glitch recovery");
  _ready = false;
  if (!begin()) {
    Serial.println("[BMP585] reinit FAILED");
    return false;
  }
  Serial.printf("[BMP585] reinit OK: p=%.2f hPa t=%.1f C\n",
                _pressure, _temperature);
  return true;
}

/**
 * @brief Take the first (blocking) reading and seed the state
 *
 * Shared by both backends (BMP585 and BMP280 fallback): fills
 * pressure/temperature/altitude, calibrates base pressure, and resets
 * the Vz derivative state.
 *
 * Base pressure calibration is median-filtered and range-validated: a
 * single corrupted sample at boot (I2C glitch, sensor mid-reset during
 * power-up) was observed to seed base_pressure ~1305 hPa, which made the
 * altitude read ~+2400 m on the pad permanently. The median of N valid
 * samples is immune to isolated corruption.
 *
 * @return true if the reading was valid
 */
bool BMP585Sensor::_firstReading() {
  float rawPressure = 0.0F;
  float rawTemp = 0.0F;

  if (_useBMP585) {
    if (!_bmp.performReading()) {
      return false;
    }
    // NOTE: performReading() already converts Pa -> hPa internally.
    // Do NOT divide by 100 again (double conversion caused alt=-62157m).
    rawPressure = _bmp.pressure;
    rawTemp = _bmp.temperature;
  } else {
    rawPressure = _bmp280.readPressure() / 100.0F;
    rawTemp = _bmp280.readTemperature();
  }

  // ── Median-filtered base pressure calibration ─────────────────────────────
  // Reject samples outside the physically plausible atmosphere (300 hPa ~
  // 9000 m; 1100 hPa ~ -900 m — the analog of the setBasePressure guard).
  // Up to N attempts; require at least MIN_VALID to accept.
  float samples[FIRST_READ_SAMPLES];
  uint8_t valid = 0;
  for (uint8_t attempt = 0;
       attempt < FIRST_READ_MAX_ATTEMPTS && valid < FIRST_READ_SAMPLES;
       attempt++) {
    if (rawPressure > 300.0F && rawPressure < 1100.0F) {
      samples[valid++] = rawPressure;
    }
    delay(FIRST_READ_SAMPLE_PERIOD_MS);
    if (_useBMP585) {
      if (!_bmp.performReading()) continue;
      rawPressure = _bmp.pressure;
      rawTemp = _bmp.temperature;
    } else {
      rawPressure = _bmp280.readPressure() / 100.0F;
      rawTemp = _bmp280.readTemperature();
    }
  }

  if (valid < FIRST_READ_MIN_VALID) {
    Serial.printf("[BMP585] Calibration failed: only %u valid pressure "
                  "samples\n", valid);
    return false;
  }

  // Insertion sort (N <= 9, trivial cost) and take the median
  for (uint8_t i = 1; i < valid; i++) {
    const float key = samples[i];
    int8_t j = i - 1;
    while (j >= 0 && samples[j] > key) {
      samples[j + 1] = samples[j];
      j--;
    }
    samples[j + 1] = key;
  }
  _basePressure = samples[valid / 2];
  _pressure = rawPressure;
  _temperature = rawTemp;
  _altitude = _useBMP585 ? _bmp.readAltitude(_basePressure)
                         : _bmp280.readAltitude(_basePressure);

  Serial.printf("[BMP585] Base pressure: %.2f hPa (%u/%u valid samples)\n",
                _basePressure, valid, FIRST_READ_SAMPLES);

  _prevAltitude = _altitude;
  _maxAltitude = _altitude;
  _prevTime = millis();
  _verticalVelocity = 0.0F;
  _spikeStreak = 0;
  return !isnan(_altitude) && !isnan(_pressure);
}
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

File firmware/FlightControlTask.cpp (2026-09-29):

/**
 * @file FlightControlTask.cpp
 * @brief Implementation of the 5Hz flight control task
 *
 * @see FlightControlTask.h for API and configuration documentation
 * @see firmware/REFACTORING_PLAN.md - Fase 7
 */

#include "flight/FlightControlTask.h"

#include <esp_task_wdt.h>
#include <esp_timer.h>
#include <ESP32Servo.h>
#include <string.h>
#include <Wire.h>

#include "config.h"
#include "sensors/BMP585Sensor.h"
#include "sensors/LSM6DS3Sensor.h"
#include "modules/parachute_module.h"
#include "flight/FlightStateMachine.h"
#include "flight/LoggerTask.h"

TaskHandle_t  g_flightControlTaskHandle = nullptr;
QueueHandle_t sensorDataQueue           = nullptr;

namespace {

// ── Sensor init retry (single shared loop for IMU + baro) ────────────────────
// Tries begin() on one sensor for up to SENSOR_INIT_RETRY_WINDOW_MS, beeping
// the buzzer on every attempt (bench-validated: the LSM6DS3/BMP585 sometimes
// only come up on a retry). Returns true on the first success.
static bool beginSensorWithRetry(ISensor* sensor, const char* name) {
  const uint32_t start = millis();
  uint32_t attempt = 0;
  for (;;) {
    attempt++;
    if (sensor->begin()) {
      if (attempt > 1) {
        Serial.printf("[FlightControl] %s init OK on attempt %lu\n",
                      name, (unsigned long)attempt);
        logMessage(TASK_ID_FLIGHT_CONTROL, LOG_LEVEL_WARN,
                   "Sensor init recovered on retry");
      }
      return true;
    }
    if (millis() - start >= SENSOR_INIT_RETRY_WINDOW_MS) {
      Serial.printf("[FlightControl] %s init failed after %lu attempts "
                    "(retry window exhausted)\n",
                    name, (unsigned long)attempt);
      return false;
    }
    Serial.printf("[FlightControl] %s init failed, retrying in %lu ms...\n",
                  name, (unsigned long)SENSOR_INIT_RETRY_PERIOD_MS);
    // Audible tick per attempt (passive piezo -> square wave via tone()).
    tone(BUZZER_PIN, BUZZER_TONE_HZ, 100);
    vTaskDelay(pdMS_TO_TICKS(SENSOR_INIT_RETRY_PERIOD_MS));
  }
}

BMP585Sensor*       g_baro = nullptr;
LSM6DS3Sensor*       g_imu = nullptr;
FlightStateMachine*  g_fsm = nullptr;

bool  g_parachuteActuated = false;

// ── Free-fall backstop state (FSM-independent safety net) ───────────────────
// Own IIR-filtered acceleration so the detector never depends on the FSM
// internals: even if the state machine is stuck (e.g. restored to ASCENT
static uint16_t g_ffSustainedCycles = 0;
static bool     g_ffFilterSeeded    = false;
static float    g_ffFiltAx = 0.0f, g_ffFiltAy = 0.0f, g_ffFiltAz = 0.0f;

// ── Barometer-staleness contingency state ───────────────────────────────────
// Own IIR filter + liftoff latch: completely independent of FSM and backstop
// state. Covers the common-mode failure where the barometer freezes mid-flight
// (frozen last-good values are plausible, never NaN) — without it, neither the
// FSM nor the free-fall backstop would deploy.
static bool     g_baroStaleFilterSeeded = false;
static float    g_bsFiltAx = 0.0f, g_bsFiltAy = 0.0f, g_bsFiltAz = 0.0f;
static bool     g_bsLiftoffLatched = false;
static uint16_t g_bsSustainedCycles = 0;

// ── Pad arming state (risk #2) ──────────────────────────────────────────────
static char     armBuffer[16] = {0};
static int      armBufferLen  = 0;

/**
 * @brief FSM-independent free-fall detector (safety backstop)
 *
 * Fires once when total acceleration (IIR-filtered, alpha=0.2) stays below
 * FREEFALL_BACKSTOP_ACC_THRESHOLD for FREEFALL_BACKSTOP_CYCLES consecutive
 * cycles while the rocket is descending faster than FREEFALL_BACKSTOP_VZ and
 * still above FREEFALL_BACKSTOP_MIN_HEIGHT. Returns true exactly once, then
 * stays latched until the next reset() (via g_ffSustainedCycles saturation).
 *
 * Covers the failure mode the NVS persistence cannot: FSM alive but stuck in
 * the wrong state (IDLE after a reboot with no valid snapshot, or ASCENT
 * while actually falling) — the chute still opens at apogee.
 *
 * @note Validated offline: extras/FSM_tester/validate_freefall_backstop.py
 *       (never fires before apogee, fires 1-3s after the FSM deploy, never
 *       on pad vibration).
 * @return true when the backstop has just fired (deploy now)
 */
bool checkFreefallBackstop() {
  // Latch: once fired, keep returning true until a reboot/reset.
  if (g_ffSustainedCycles > FREEFALL_BACKSTOP_CYCLES) {
    return true;
  }

  float ax, ay, az;
  g_imu->getAcceleration(&ax, &ay, &az);

  if (!std::isfinite(ax) || !std::isfinite(ay) || !std::isfinite(az)) {
    return false;
  }

  // IIR low-pass, same alpha as the FSM (seed on first reading).
  if (!g_ffFilterSeeded) {
    g_ffFiltAx = ax;
    g_ffFiltAy = ay;
    g_ffFiltAz = az;
    g_ffFilterSeeded = true;
  } else {
    g_ffFiltAx += FILTER_ALPHA * (ax - g_ffFiltAx);
    g_ffFiltAy += FILTER_ALPHA * (ay - g_ffFiltAy);
    g_ffFiltAz += FILTER_ALPHA * (az - g_ffFiltAz);
  }

  const float acc = sqrtf(g_ffFiltAx * g_ffFiltAx +
                          g_ffFiltAy * g_ffFiltAy +
                          g_ffFiltAz * g_ffFiltAz);
  if (!std::isfinite(acc)) {
    return false;
  }

  const float height = g_baro->getAltitude();
  const float vz     = g_baro->getVerticalVelocity();

  const bool freefalling = (acc < FREEFALL_BACKSTOP_ACC_THRESHOLD &&
                            vz  < FREEFALL_BACKSTOP_VZ &&
                            height > FREEFALL_BACKSTOP_MIN_HEIGHT);
  if (freefalling) {
    g_ffSustainedCycles++;
    if (g_ffSustainedCycles == FREEFALL_BACKSTOP_CYCLES) {
      Serial.printf("[FlightControl] BACKSTOP: free-fall acc=%.2f vz=%.2f h=%.1f\n",
                    acc, vz, height);
      return true;
    }
  } else {
    g_ffSustainedCycles = 0;
  }
  return false;
}
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

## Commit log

2026-01-15 Docs: add flowchart
2026-01-27 docs: create CHANGELOG and CONTRIBUTING guidelines
    - Add CHANGELOG.md following Keep a Changelog format
    - Add CONTRIBUTING.md with contribution guidelines and code standards
    - Translate all documentation to English (README, CHANGELOG, CONTRIBUTING, software/hardware docs, flowchart, BOM)
    - Establish Semantic Versioning for project releases
    - Define code style standards (2-space indentation, camelCase, English comments)
    - Add contribution workflow with branch naming and PR checklist guidelines
    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
2026-01-27 docs: add V2 development notes and scaffold structure
    [13_30_11-Dados.csv, CDB.fzz, CDB.kicad_pcb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]
